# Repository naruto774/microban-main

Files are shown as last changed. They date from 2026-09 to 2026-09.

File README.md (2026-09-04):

# Microban: A Compact, Fully 3D-Printable Open-Source Humanoid Robot





<p align="center">
  
  
  
</p>
  
Welcome to the **Microban** project! 

Microban is a ~30cm tall open-source humanoid robot created by [Marc Duclusaud](https://github.com/MarcDcls) as a member of the Rhoban team at LaBRI, University of Bordeaux, and designed specifically for makers, students, and robotics enthusiasts. The core philosophy behind this project is accessibility: the total cost of the robot is kept relatively low ($550-$600), all components are 3D-printable or easily sourced, and the assembly process is guided with detailed instructions. This means that anyone with a standard desktop 3D printer and a few basic tools should be able to build their own Microban from scratch.

The idea behind Microban is to provide a platform for learning and experimentation in robotics. By making the design open, users are encouraged to modify, improve, and share their own versions of the robot. Whether you're interested in programming, mechanical design, or electronics, Microban offers a hands-on experience that can help you develop your skills in a fun and engaging way.

The main features of Microban are:
*   🤖 **100% Open-Design**: Mechanics, 3D models, and documentation are entirely free to use and modify.
*   🔧 **DIY & Maker Friendly**: Guided assembly instructions, fully 3D-printable parts and cheap components.
*   📏 **Compact Size**: Microban is only 30cm tall and can be recharged via USB-C, making it the perfect desktop companion for robotics experimentation.

To see the robot take its first steps, check out this YouTube video: [https://youtu.be/1pnFrT_jfXQ](https://youtu.be/1pnFrT_jfXQ)

---

## 🛠️ Components Overview

Here is a quick overview of what is in the robot:

| Component | Quantity | Description / Notes |
| :--- | :---: | :--- |
| **3D Printed Parts** | ~30 | Check the CAD files. Recommended material is PLA. |
| **Servo Motors** | 19 | Dynamixel XL330-M288-T servomotor. |
| **Microcontroller**| 1 | Raspberry Pi Zero 2W. |
| **Board Hat** | 1 | Pollen RPI Robot Hat for Raspberry Pi Zero 2W. |
| **Power Supply** | 2 | 18650 3.7V Lithium-ion Batteries. |
| **Battery Holder** | 1 | 2x18650 Battery Holder. |
| **USB-C Charger** | 1 | Standard USB-C charger. |
| **BMS** | 1 | Battery Management System for 2x18650 batteries. |
| **Plastic Screws**| ~200 | Standard plastic screws for assembly. |
| **Steel & POM Shims** | 12 | Alternative to needle bearings for motors without idler horns. | 

A full, detailed Bill Of Materials (BOM) with links to purchase and prices is available [here](docs/bom.md)

---

## 📁 CAD Files

Capture d’écran du 2026-06-15 13-33-16

The CAD files for Microban are in the `cad/` directory of this repository. It contains all the printable parts in both STL and STEP formats.

A visual representation of the 3D model can be found in the [Onshape assembly](https://cad.onshape.com/documents/d424992a192a8ce34ffce163/v/7de3e6e40f0e1185d169e6d9/e/b34620a03cc3a684006c5867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). This interactive assembly allows you to explore the robot's design in detail, providing a better understanding of how the parts fit together. It also serves as a reference for assembly, helping you visualize the final product and ensuring that you can correctly identify each component during the build process.

An emphasis is placed on the range of motion of the 19 degrees of freedom of the robot. It allows for a wide variety of movements, making it suitable for various applications. Stops are integrated into the design to control which self-collisions are likely to occur, ensuring that the robot can move safely without damaging itself. The design also takes into account the cable routing for the servo motors, ensuring that the wires are neatly organized and do not interfere with the robot's movements.

---

## 🚀 Getting Started 

> **Need help during the build?** 
> If you run into any issues while sourcing components, printing parts, or assembling your Microban, don't hesitate to ask the community in the **[Q&A Discussions section](https://github.com/Rhoban/microban/discussions/categories/q-a)**!

To build your own Microban, you will need to follow these steps:

1. **Source the hardware:** Gather the components listed in the [BOM](docs/bom.md). Links are provided to purchase each item, but feel free to source them from your preferred suppliers. Some components, like the Dynamixel motors, may have specific distributors depending on your location, which can impact the total cost. 

2. **Print the parts:** Head over to the `cad/stl/` folder and print all the parts using a 3D printer. The recommended filament is PLA with a layer height of 0.12mm and a 15% infill. Some parts require specific orientations for printing to ensure strength and proper fit. Refer to the [Printing Guide](docs/printing.md) for detailed instructions on how to print each part correctly.

3. **Assemble:** Follow our step-by-step [Assembly Guide](docs/assembly.md) to put the mechanics together.

4. **Deploy the software:** Once the robot is assembled, you can deploy the software on the Raspberry Pi Zero 2W by following the instructions in the [Deployment Guide](docs/deployment.md). 

5. **Drive it:** See the [Usage Guide](docs/usage.md) to run the robot, control it with the keyboard or a gamepad, and learn how to add your own moves.

---

## 🤝 Contributing

This project is community-driven! Whether it's designing a new head, writing code, or simply fixing typos in the documentation, contributions are always welcome. Feel free to fork the repository, make your changes, and submit a Pull Request. 

If you build your own Microban, don't hesitate to share it in the **[Show and Tell section](https://github.com/Rhoban/microban/discussions/categories/show-and-tell)**! 

If you just want to share ideas or chat about the project, you are also more than welcome to join the **[General Discussions](https://github.com/Rhoban/microban/discussions/categories/general)**.

---

## 📄 License & Commercial Use

Copyright (c) 2026 Marc Duclusaud.

This project uses a dual-licensing model to keep the project open for the community while protecting the author's work from unauthorized commercial exploitation.

* **Hardware & Documentation (CAD, STL, Docs):** Licensed under [CC BY-NC-SA 4.0](https://creativecommons.org/licenses/by-nc-sa/4.0/).
* **Software (Source Code):** Licensed under [GNU GPL v3](https://www.gnu.org/licenses/gpl-3.0.html).

To summarize the licenses:

* **Hobbyists, Makers & Researchers:** You are **100% free** to download, 3D-print, build, modify, and hack Microban for your personal, educational, or academic research use. If you share your modifications, you must release them under the same licenses.
* **Commercial Entities & Companies:** You **cannot sell this robot**, sell parts/kits, or use this hardware/software design in commercial products without prior explicit written permission.

### ⚠️ Commercial Inquiries

If you wish to manufacture, distribute, or sell products based on Microban (including selling pre-printed 3D parts, electronics kits, or fully assembled robots), you **must acquire a Commercial License**.

For licensing terms, commercial partnerships, or inquiries, please reach out to me on [LinkedIn](https://www.linkedin.com/in/marc-duclusaud/).

---

## 📚 Citation

If you use Microban in your research, please cite it as follows:

```bibtex
@software{mduclusaud-microban,
    author = {Duclusaud, Marc},
    doi = {10.5281/zenodo.20784789},
    month = jun,
    title = {{Microban: A Compact, Fully 3D-Printable Open-Source Humanoid Robot}},
    url = {https://github.com/Rhoban/microban},
    howpublished = "\url{https://github.com/Rhoban/microban}",
    version = {1.0.0},
    year = {2026}
}
```

---

<p align="center">
  
</p>

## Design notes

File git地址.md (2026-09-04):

# Git 远程仓库地址

## 仓库

- URL：https://github.com/naruto774/microban-main
- 可见性：Private
- 账号：`naruto774`
- 分支：`main`（已推送并跟踪 `origin/main`）

## 代理与 PATH（本机已配置）

| 配置项 | 值 |
|---|-----|
| 系统 / Git 代理 | `http://127.0.0.1:7897` |
| `gh` 路径 | `C:\Program Files\GitHub CLI\` |

当前终端若找不到 `gh`，先执行：

```powershell
$env:Path += ";C:\Program Files\GitHub CLI\"
$env:HTTP_PROXY = "http://127.0.0.1:7897"
$env:HTTPS_PROXY = "http://127.0.0.1:7897"
```

## 常用命令

```powershell
git pull
git push
gh repo view --web
```

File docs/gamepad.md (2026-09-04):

# Gamepad control through Bluetooth

The robot can be driven with a Bluetooth gamepad (Xbox or compatible). The gamepad
is paired with the Raspberry Pi and read directly there via the Linux joystick API
(`/dev/input/js*`), in the same process as the control loop. 

Pairing a gamepad allows to drive the robot through two different modes: with a terminal (SSH) or fully headless (no SSH, no terminal). The second mode is particularly useful for demonstration purposes, 
due to the fact that it allows to drive the robot without any computer connected to it. 

## Pairing the controller on the Pi

On the Pi, put the Xbox controller in pairing mode (hold the pair button until the
Xbox light flashes fast), then:

```
bluetoothctl
[bluetooth]# power on
[bluetooth]# agent on
[bluetooth]# scan on        # wait for the "Xbox Wireless Controller" MAC to appear
[bluetooth]# pair  XX:XX:XX:XX:XX:XX
[bluetooth]# trust XX:XX:XX:XX:XX:XX    # auto-reconnect on next power-on
[bluetooth]# connect XX:XX:XX:XX:XX:XX
[bluetooth]# scan off
[bluetooth]# quit
```

Once paired and trusted, the controller reconnects automatically when powered on.

## SSH usage

When the controller is connected, the `make run` command uses it as input automatically instead of the keyboard. The mapping is:

- **Left stick**: `vx` (up/down), `vy` (left/right)
- **Right stick** (left/right): `vtheta`
- **A**: toggle the `walk` move
- **B**: stop the scheduler (writes the stop flag)
- **View/Back** button: toggle the IMU/gyro display

Axis and button numbers vary between controllers (especially over Bluetooth) — if
something doesn't respond as expected, see [Remapping](#remapping-for-your-controller).

Every input source emits a **normalized** command in `[-1, 1]` per axis. The physical
limits are applied centrally by `scale_velocity()` in the scheduler, so they are
identical for keyboard, gamepad and sim: `vx` ±0.7, `vy` ±0.3, `vtheta` ±3.0 when
turning in place (`vx = vy = 0`) and ±1.5 while translating. Tune these via
`VX_MAX` / `VY_MAX` / `VTHETA_MAX_STATIONARY` / `VTHETA_MAX_MOVING` in
[constants.py](../src/constants.py).

Signs, deadzone and button mapping are constants at the top of
[gamepad_input.py](../src/input/gamepad_input.py); the move/button mapping is set
via `GAMEPAD_BUTTON_MOVES` in [main.py](../src/main.py).

## Headless mode (no SSH)

The headless mode is an optional service that lets you run the robot **without any terminal**. To activate it, power off the controller, then run the following commands on your computer:

```
make gamepad-headless-enable
```

Once enabled, it launches a daemon on the Pi that waits for a controller to connect over Bluetooth. Once a controller is connected, the Wi-Fi is turned off to free the 2.4 GHz antenna and the following commands are available on the controller:

- **Hold START** → start the control loop.
- **A** → toggle the `walk` move.
- **B** → stop the control loop.
- **Hold both triggers** → power off the Pi cleanly. Wait 10-15 s after that before
  flipping the robot's power switch off, to give the Pi time to actually halt.

The headless mode persists across reboots, which means that you don't need to connect to the Pi over SSH to enable it again. It is particularly useful for demonstration purposes, as it allows to drive the robot without any computer connected to it.

If the **controller disconnects** during a session, the robot's velocity is zeroed so
it stops moving (torque stays on, holding its pose). Reconnect and press **B** or power off the robot end the session.

Whenever the daemon is left with no controller connected — because it disconnected,
because the control loop crashed, or because the robot just booted — Wi-Fi is
(re)enabled automatically. You don't need to power-cycle the robot to get SSH back;
simply turning the controller off is enough.

> [!IMPORTANT]
> As the Wi-Fi is turned off when the controller is connected, so you won't be able to connect to the Pi over SSH while the controller is connected. If you need to connect to the Pi over SSH, power off the controller

To disable the headless mode, run the following command (after powering off the controller):
```
make gamepad-headless-disable
```

## Remapping for your controller

Xbox controllers don't all expose the same axis/button numbers — over Bluetooth the
kernel often uses a different layout than the wired `xpad` one. If a stick or button
doesn't behave as expected, find the real numbers and update the constants.

This requires an SSH session, so headless mode must be disabled first (see above) —
otherwise Wi-Fi is off while the controller is connected and you won't be able to
reach the Pi. You'll also need the controller connected.

1. Install the joystick package on the Pi:
```
sudo apt install -y joystick
```

2. Run `jstest /dev/input/js0`, then move each stick and press each button one at a
   time, noting the `Axis N` / `Button N` that changes:

   | Action | Note the number |
   | :--- | :--- |
   | Left stick horizontal / vertical | `Axis` → `_AXIS_LX` / `_AXIS_LY` |
   | Right stick horizontal | `Axis` → `_AXIS_RX` (drives `vtheta`) |
   | A / B / Back / Start | `Button` → `XBOX_BUTTONS` |
   | Left / right trigger | `Axis` → `TRIGGER_AXES` (headless power-off gesture) |

3. Edit the constants at the top of
   [gamepad_input.py](../src/input/gamepad_input.py):
   - `_AXIS_LX`, `_AXIS_LY`, `_AXIS_RX` — the stick axis numbers.
   - `XBOX_BUTTONS` — the button name → number map (at least the ones you use).
   - `TRIGGER_AXES` — the `LT` / `RT` axis numbers, and `TRIGGER_PRESS_THRESHOLD` —
     the raw axis value that counts as "pressed".
   - `VX_SIGN`, `VY_SIGN`, `VTHETA_SIGN` — flip between `+1.0` / `-1.0` if a direction
     is reversed.

4. Which button does what is set by `GAMEPAD_BUTTON_MOVES` in
   [main.py](../src/main.py) (moves) and the `stop_button` / `imu_button` arguments of
   `GamepadInputSource` (defaults: stop = `B`, IMU = `BACK`).

The defaults shipped in the repo (A=0, B=1, Start=11; left stick = axes 0/1, right
stick horizontal = axis 2, triggers = axes 4/5) are verified on an Xbox controller
over Bluetooth — but the exact axis numbers, rest/press values and button mappings are known to vary
across pads, so double-check with `jstest` on yours.

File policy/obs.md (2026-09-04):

针对 run `2026-08-27_14-43-05_motrix`（`run_config.json` 已确认：`empirical_normalization=true`，`action_scale=0.15`），整理如下。

---

## 1. 观测拼接代码

核心在 `MICROBANWalkEnv._compute_obs()`：

```407:463:src/unilab/envs/locomotion/microban/joystick.py
    def _compute_obs(
        self, info: dict, linvel, gyro, gravity, dof_pos, dof_vel
    ) -> dict[str, np.ndarray]:
        noise_cfg = self._cfg.noise_config
        diff = dof_pos - self.default_angles
        command = info["commands"]
        last_actions = info.get("current_actions", np.zeros_like(diff))
        gait_phase = info.get("gait_phase", np.zeros((self._num_envs, 2), dtype=get_global_dtype()))
        walk_profile = self._uses_walk_observation_profile()

        noisy_gyro = self._obs_noise(gyro, noise_cfg.scale_gyro)
        noisy_gravity = self._obs_noise(gravity, noise_cfg.scale_gravity)
        noisy_diff = self._obs_noise(diff, noise_cfg.scale_joint_angle)
        noisy_dof_vel = self._obs_noise(dof_vel, noise_cfg.scale_joint_vel)
        actor_gyro_scale = 0.25 if walk_profile else 1.0
        actor_dof_vel_scale = 0.05 if walk_profile else 1.0

        actor = np.concatenate(
            [
                noisy_gyro * actor_gyro_scale,
                -noisy_gravity,
                noisy_diff,
                noisy_dof_vel * actor_dof_vel_scale,
                last_actions,
                command,
                gait_phase,
            ],
            axis=1,
            dtype=get_global_dtype(),
        )
        # ... critic 分支省略 ...
        return {"obs": actor, "critic": critic}
```

传感器来源（`update_state`）：

```370:375:src/unilab/envs/locomotion/microban/joystick.py
        linvel = self.get_local_linvel()
        gyro = self.get_gyro()
        gravity = self._backend.get_sensor_data(self._cfg.sensor.upvector)
        dof_pos = self.get_dof_pos()
        dof_vel = self.get_dof_vel()
```

对应 `Sensor` 配置（`base.py`）→ XML 传感器名：

| 变量 | 传感器名 | XML 挂载 site |
|---|---|---|
| `gyro` | `trunk_gyro` | `body`（躯干原点） |
| `gravity` | `trunk_upvector` | `body` |
| `linvel`（仅 critic） | `trunk_local_linvel` | `body` |

---

## 2. Actor 观测 47 维布局（该 run 的实际缩放）

该 run 的 reward scales 含 `orientation / ang_vel_xy / action_rate`，因此 **`walk_profile = False`**，gyro/dof_vel **不做 0.25/0.05 缩放**。

| 索引 | 维度 | 内容 | 该 run 处理 |
|---|---|---|---|
| 0–2 | 3 | 角速度 `trunk_gyro` | `+ noise(×0.2)`，×**1.0** |
| 3–5 | 3 | 重力方向 | `-trunk_upvector`，`+ noise(×0.05)` |
| 6–17 | 12 | `dof_pos - default_angles` | `+ noise(×0.01)` |
| 18–29 | 12 | `dof_vel` | `+ noise(×1.5)`，×**1.0** |
| 30–41 | 12 | 上一步 action（`current_actions`） | 无噪声 |
| 42–44 | 3 | command `[vx, vy, ωz]` | 无噪声 |
| 45–46 | 2 | gait_phase `[φ_L, φ_R]` (rad) | 无噪声 |

**关节 / action 顺序**（与 actuator 一致，右腿在前）：

```
right_hip_yaw, right_hip_roll, right_hip_pitch, right_knee,
right_ankle_pitch, right_ankle_roll,
left_hip_yaw, left_hip_roll, left_hip_pitch, left_knee,
left_ankle_pitch, left_ankle_roll
```

**动作后处理**（部署需一致）：

\[
q_{\text{target}} = a \times 0.15 + q_{\text{default}}
\]

其中 `q_default` 来自 keyframe `stand` 的 ctrl（全 0，即 CAD 零位站立姿）。

**Command 范围**（训练采样，`vel_limit`）：

```
vx: [0.1, 0.40],  vy: [0.0, 0.0],  ωz: [-0.1, 0.1]
```

死区 `command_threshold=0.1` 内视为站立，command 清零、gait_phase 冻结。

---

## 3. ONNX input shape / metadata

导出路径：`scripts/train_rsl_rl.py` play 时调用 `runner.export_policy_to_onnx()`，写入 run 目录。该 run 下 **`policy.onnx` 已存在**。

RSL-RL 5.0.1 的 ONNX 封装（`_OnnxMLPModel`）规范：

| 字段 | 值 |
|---|-----|
| **input name** | `"obs"` |
| **input shape** | `(N, 47)`，trace 时用 `(1, 47)` |
| **output name** | `"actions"` |
| **output shape** | `(N, 12)` |
| **opset** | 18 |
| **normalization** | `empirical_normalization=true` → **Normalizer 已 bake 进图内**，部署侧喂**原始 47 维**（与训练拼接一致，**不加训练噪声**） |
| **output 语义** | Gaussian policy 的 **deterministic mean**（非采样） |

该 run 的 `run_config.json` 关键字段：

```json
"empirical_normalization": true,
"env.control_config.action_scale": 0.15,
"obs_groups": { "actor": ["actor"], "critic": ["critic"] }
```

**注意**：ONNX 图本身**不含** obs 布局 metadata（无 `deploy_config.yaml` 那种 segment 描述）；布局需按上文 47 维表手动对齐。Critic 的 50 维（含 linvel×1.0）**不会**导出到 policy ONNX。

---

## 4. 训练模型中 IMU 的安装位置

XML 里有两套 site，用途不同：

### A. 策略实际使用的传感器 — `body` site（躯干原点）

```65:67:src/unilab/assets/robots/microban/microban.xml
      <site group="3" name="body" pos="0 0 0" quat="1 -0 -0 -0"/>
      <!-- Frame imu -->
      <site group="3" name="imu" pos="0.01483 -0.002 0.0675" quat="0.5 -0.5 -0.5 0.5"/>
```

```38:40:src/unilab/assets/robots/microban/microban.xml
    <velocimeter site="body" name="trunk_local_linvel"/>
    <gyro site="body" name="trunk_gyro"/>
    <framezaxis objtype="site" objname="body" name="trunk_upvector"/>
```

**训练 policy 的 gyro / gravity 来自 `body` site（trunk 坐标系原点），不是 `imu` site。**

### B. 物理 IMU 建模 site — `imu` site（仅 XML 定义，未进 policy obs）

- **父 body**：`trunk`
- **相对 trunk 原点位置**：`(0.01483, -0.002, 0.0675)` m → **x=+14.8 mm，y=-2 mm，z=+67.5 mm**（约在躯干上部/胸廓区域）
- **姿态**：`quat="0.5 -0.5 -0.5 0.5"`（相对 trunk 有 90° 轴旋转）
- **挂载传感器**：`imu_ang_vel`、`imu_lin_vel`、`imu_accel`、`orientation`（framequat）

这些 **`imu_*` 传感器未接入 `_compute_obs()`**，当前 walk 策略观测与 **`body` 原点 IMU 等效**，而非真实 IMU 安装点。

---

## 5. 部署对齐 checklist

1. 按 47 维表拼接 obs（**无训练噪声**）
2. ONNX 输入 `(1, 47)` → 输出 `(1, 12)`
3. `q_target = action × 0.15 + default_angles`
4. 自研 IMU 若在 `(14.8, -2, 67.5) mm` 且 frame 与 XML `imu` quat 一致，需 **变换到 trunk 原点 frame** 才能与训练分布对齐；否则 sim-to-real 会有系统偏差

步态相位 **不是从足端接触或关节角反推的**，而是一个 **开环、固定频率的虚拟时钟**，由 env 在 `info["gait_phase"]` 里维护，再直接拼进观测的最后 2 维。

---

## 数学定义

记左右腿相位为 \(\phi_L, \phi_R \in [0, 2\pi)\)，每控制步更新：

\[
\begin{bmatrix} \phi_L \\ \phi_R \end{bmatrix}
\leftarrow
\left(
\begin{bmatrix} \phi_L \\ \phi_R \end{bmatrix}
+
\Delta\phi \cdot \mathbf{1}_{\|\mathbf{cmd}\| > \tau}
\right) \bmod 2\pi
\]

其中：

- \(\Delta\phi = 2\pi \cdot f_{\text{gait}} \cdot \Delta t\)
- \(f_{\text{gait}}\) = `reward.gait_frequency`（你的 run 为 **1.4 Hz**）
- \(\Delta t\) = `ctrl_dt`（Microban 为 **0.02 s**）
- \(\tau\) = `command_threshold`（**0.1**）
- \(\mathbf{cmd} = [v_x, v_y, \omega_z]\)

代入你的 run：

\[
\Delta\phi = 2\pi \times 1.4 \times 0.02 \approx 0.176 \text{ rad/step} \approx 10.1°/\text{step}
\]

---

## 代码流程

### 1. Reset 时初始化

默认 `gait_phase_init_mode = "offset_phase"`（左右腿相差 \(\pi\)，标准交替步态）：

```260:268:src/unilab/envs/locomotion/microban/joystick.py
    def _sample_gait_phase(self, env: Any, num_reset: int) -> np.ndarray:
        mode = env.cfg.gait_phase_init_mode
        if mode == "independent":
            left = np.random.uniform(0.0, 2.0 * np.pi, size=(num_reset,))
            right = np.random.uniform(0.0, 2.0 * np.pi, size=(num_reset,))
            return np.asarray(np.column_stack([left, right]), dtype=get_global_dtype())

        phase = np.random.uniform(0.0, 2.0 * np.pi, size=(num_reset,))
        return np.asarray(np.column_stack([phase, phase + np.pi]), dtype=get_global_dtype())
```

即：

\[
\phi_L \sim U[0, 2\pi),\quad \phi_R = \phi_L + \pi \pmod{2\pi}
\]

若 `mode == "independent"`，左右腿各自独立均匀采样。

### 2. 每步在 `apply_action` 里推进

```305:307:src/unilab/envs/locomotion/microban/joystick.py
        self._gait_phase_delta = float(
            2.0 * math.pi * self._reward_cfg.gait_frequency * cfg.ctrl_dt
        )
```

```652:666:src/unilab/envs/locomotion/microban/joystick.py
    def apply_action(self, actions: np.ndarray, state: NpEnvState) -> np.ndarray:
        ...
        moving = compute_gait_command_gate(
            state.info.get("commands", ...),
            self._cfg.command_threshold,
        )
        gait_phase = (gait_phase + self._gait_phase_delta * moving[:, None]) % (2 * np.pi)
        state.info["gait_phase"] = gait_phase
```

`moving` 判定：

```131:133:src/unilab/envs/locomotion/microban/joystick.py
def compute_gait_command_gate(commands: np.ndarray, threshold: float) -> np.ndarray:
    """Enable phase-driven gait behavior only for commands outside the stand deadzone."""
    return np.asarray(np.linalg.norm(commands, axis=1) > threshold, dtype=get_global_dtype())
\]

**站立时**（\(\|\mathbf{cmd}\| \le 0.1\)）：相位 **冻结**，不再递增。测试也验证了这一点。

### 3. 拼进观测

```414:432:src/unilab/envs/locomotion/microban/joystick.py
        gait_phase = info.get("gait_phase", np.zeros((self._num_envs, 2), dtype=get_global_dtype()))
        ...
        actor = np.concatenate(
            [
                ...
                command,
                gait_phase,   # obs[45:47] = [φ_L, φ_R]
            ],
```

观测里是直接喂 **原始弧度值**，没有 `sin/cos` 编码。

---

## 相位在 reward 里的语义（与 obs 共用同一变量）

同一 `gait_phase` 还通过 Bezier 曲线映射成左右脚 **期望摆动高度**，用于 `feet_phase` 等 reward：

```73:95:src/unilab/envs/locomotion/microban/joystick.py
def compute_feet_phase_height_targets(gait_phase, swing_height):
    # φ 归一化到 [-π, π)，再映射到 [0,1]
    phi_normalized = np.fmod(phi + np.pi, 2 * np.pi) - np.pi
    x = (phi_normalized + np.pi) / (2 * np.pi)
    # x ∈ [0, 0.5]: 支撑→抬脚;  x ∈ (0.5, 1]: 摆荡→落脚
```

直观理解一个周期（以单腿为例）：

| 相位区间 | 含义 |
|---|---|
| \(\phi \in [0, \pi)\) | 支撑相 → 抬脚（高度 0 → `swing_height`） |
| \(\phi \in [\pi, 2\pi)\) | 摆动相 → 落脚（高度 `swing_height` → 0） |

左右腿初始相差 \(\pi\)，所以一腿支撑时另一腿摆动。

---

## 部署侧注意

1. **必须自己维护** `gait_phase` 状态，不能指望 IMU/关节反推。
2. 用同一公式推进：\(\phi \leftarrow (\phi + \Delta\phi \cdot \mathbb{1}_{moving}) \bmod 2\pi\)。
3. `moving` 判定要与训练一致：command 范数 **> 0.1** 才推进。
4. Reset 时建议用 `offset_phase` 初始化（\(\phi_R = \phi_L + \pi\)），与训练分布一致。
5. 相位是 **理想时钟**，与实际足端触地可能不同步；策略学的是「跟着这个时钟走」。

如果你需要，我可以再写一段可直接用于 C++/Python 部署的 `gait_phase` 更新伪代码。

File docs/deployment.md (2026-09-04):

# Software Installation & Deployment

This guide takes you from the pre-built Microban SD-card image to a robot you can drive
from your computer. The image already contains the operating system and the Microban
code; you will flash it, connect to the robot over the network, and run it. For
day-to-day operation and development afterwards, see the [Usage Guide](usage.md).

## Step 1: Download and Flash the Image

Download `microban.img.xz` from the
[latest image release](https://github.com/MarcDcls/microban/releases/tag/image.v2)
([direct link](https://github.com/MarcDcls/microban/releases/download/image.v2/microban.img.xz)).
There is no need to decompress it; Raspberry Pi Imager reads the compressed `.xz`
directly.

Then use [Raspberry Pi Imager](https://www.raspberrypi.com/software/) to write
`microban.img.xz` onto a micro-SD card. The card should be 16 GB or larger, and I
advise using a new card, as corrupted cards can cause issues.

1. Insert the micro-SD card into your computer.
2. Open Raspberry Pi Imager. It is distributed as an AppImage, so make it executable
   and run it as root to let it write to the SD card:
   ```bash
   chmod +x Downloads/imager_*.AppImage
   sudo Downloads/imager_*.AppImage
   ```
3. **Choose Device** → *Raspberry Pi Zero 2 W*.
4. **Choose OS** → scroll to the bottom and select *Use custom*, then pick the
   `microban.img.xz` file.
5. **Choose Storage** → select your micro-SD card.
6. Click **Next**. When asked *"Would you like to apply OS customisation settings?"*,
   choose **No** — the image is already configured (the Wi-Fi is set up in Step 2).
7. Click **Write** and wait for the flashing and verification to complete.

> Alternatively, on Linux you can flash from the command line. **Double-check the
> device name** (`lsblk`) — writing to the wrong disk will erase it:
> ```bash
> xzcat microban.img.xz | sudo dd of=/dev/sdX bs=4M status=progress conv=fsync
> ```

## Step 2: Headless Wi-Fi Configuration

Once the flashing process is complete, unplug and plug back the micro-SD card into your Ubuntu PC.

Open your terminal and open the network configuration file using nano:

```bash
sudo nano /media/$USER/bootfs/network-config
```

You should see a YAML file with the following content:

```yaml
network:
  version: 2
  ethernets:
    eth0:
      dhcp4: true
      dhcp6: true
      optional: true
  wifis:
    wlan0:
      dhcp4: true
      regulatory-domain: "<YOUR_COUNTRY_CODE>"
      access-points:
        "<YOUR_WIFI_NAME>":
          password: "<YOUR_WIFI_PASSWORD>"
      optional: true
```

⚠️ CRITICAL: DO NOT modify the YAML format. It is strictly space-sensitive and should not be changed. 

📶 CRITICAL: the network **must be 2.4 GHz**. The Raspberry Pi Zero 2 W has a 2.4 GHz-only
Wi-Fi chip and **cannot see or join a 5 GHz network** — it will silently never connect. If
you use a phone hotspot, force it to 2.4 GHz.

🛜 Replace <YOUR_WIFI_NAME> and <YOUR_WIFI_PASSWORD> with your local network credentials. In addition, you can set other networks, such as your phone hotspot to use your robot everywhere. To do so, add an entry to the access-points section:

```yaml
      access-points:
        "<YOUR_WIFI_NAME>":
          password: "<YOUR_WIFI_PASSWORD>"
        "<YOUR_SECOND_WIFI_NAME>":
          password: "<YOUR_SECOND_WIFI_PASSWORD>"
```

🌍 Don't forget to replace <YOUR_COUNTRY_CODE> with your local two-letter country code (ISO 3166-1 alpha-2). For example, use "US" for the United States, "GB" for the United Kingdom, "FR" for France, "DE" for Germany, etc. This ensures the Raspberry Pi uses the correct Wi-Fi channels allowed in your country.

Save and exit (Ctrl + O, then Enter, then Ctrl + X).

Safely eject the card from your Ubuntu PC, insert it into the Raspberry Pi Zero 2W, and power it up.

> **Changing the Wi-Fi networks later:** just edit `network-config` again — on the Pi,
> or offline with the SD card in your PC — and reboot. The robot detects the change at
> boot and re-applies it automatically (it resets cloud-init and reboots once). 

## Step 3: First SSH Connection

Give the Raspberry Pi about 1 to 2 minutes on its very first boot. It will automatically resize the file system to use the full capacity of your SD card and then connect to your Wi-Fi network. Do not power it off during this process, as it may take a while and interrupting it could cause issues.

When the Pi is ready, you should be able to ping it from your computer using the command:

```bash
ping microban.local
```

You should see a response looking like this:
```
PING microban.local (192.168.XXX.XX) 56(84) bytes of data.
64 bytes from 192.168.XXX.XXX: icmp_seq=1 ttl=64 time=100 ms
...
```

The default credentials of this image are:
- Username: `user`
- Password: `password`

Open your terminal and connect over SSH:

```bash
ssh user@microban.local
```

> If `microban.local` cannot be found after 5 minutes, look up your local router's DHCP client list
> to find the IP address assigned to the Pi, and connect with `ssh user@<IP>`.

## Step 4: Personalize and Secure Your Robot

Once you are successfully connected via SSH, change the default password and,
optionally, customize the hostname.

### Change the password

Run the password tool and follow the prompts:
```bash
passwd
```

Apply the changes:
```bash
sudo reboot
```

### OPTIONAL - Change the username

The image ships with the user `user`. A logged-in account cannot be renamed, so create
a temporary admin account, rename from there, then remove it. Replace `NEW_USER` with
your choice.

From the default `user` session, create a temporary admin and set its password:
```bash
sudo useradd -m -s /bin/bash -G sudo tmpadmin
sudo passwd tmpadmin
```
Log out, reconnect as `tmpadmin`, then rename the original account:
```bash
ssh tmpadmin@<ROBOT_IP>
sudo usermod -l NEW_USER -d /home/NEW_USER -m user
sudo groupmod -n NEW_USER user      # rename its primary group too
```
Log out, reconnect as `NEW_USER`, and delete the temporary account:
```bash
ssh NEW_USER@<ROBOT_IP>
sudo userdel -r tmpadmin
```
The shutdown-without-password rule still works (it targets the `sudo` group, not a
name). Remember to update the `User` field in your `~/.ssh/config` (Step 5).

Apply the changes:
```bash
sudo reboot
```

### OPTIONAL - Change the hostname

Rename your robot so it no longer answers to `microban` on the network:
```bash
sudo hostnamectl set-hostname NEW_ROBOT_NAME
```
Then update the hosts file to match:
```bash
sudo nano /etc/hosts
```
Find the line containing `microban` (usually the second line) and replace it with your
`NEW_ROBOT_NAME`. Save and exit (Ctrl+O, Enter, Ctrl+X).

Apply the changes:
```bash
sudo reboot
```

## Step 5: Deploy the Software from Your Computer

The code already ships on the robot, but you drive and update it from your computer
using the provided `Makefile`, which syncs your local copy to the Pi over SSH and
installs the dependencies there.

1. **Install [uv](https://docs.astral.sh/uv/)** (the Python package manager) on your
   computer:
   ```bash
   curl -LsSf https://astral.sh/uv/install.sh | sh
   ```

2. **Clone the repository** on your computer:
   ```bash
   git clone https://github.com/MarcDcls/microban.git
   cd microban
   ```

3. **Add SSH aliases** so the Makefile can reach the Pi. Add the following to your
   `~/.ssh/config`, replacing `user` if you changed it and `<IP_ADDRESS>` with the
   robot's IP on each network:
   ```
   # Main network
   Host microban
       HostName <IP_ADDRESS>
       User user

   # Secondary network / phone hotspot
   Host microban-ext
       HostName <IP_ADDRESS>
       User user
   ```
   To find the robot's IP on a given network ping it from your computer while connected to that network:
   ```bash
   ping microban.local
   ```

   > The Makefile targets default to `HOST=microban`. To operate the robot over the
   > secondary network, pass `HOST=microban-ext` (e.g. `make run HOST=microban-ext`),
   > or export it for the whole session: `export HOST=microban-ext`.

4. **Copy your SSH key** (recommended) so you are not prompted for a password on every
   command:
   ```bash
   ssh-keygen -t ed25519     # skip if you already have a key
   ssh-copy-id microban
   ```

5. **Push the code and install dependencies** on the Pi:
   ```bash
   make setup
   ```
   This rsyncs your local copy to the robot and runs `uv sync --frozen` there.

## Step 6: Run the Robot

Your Microban is ready! Place it on a stable surface (or hold it securely), then start
the control loop from your computer:

```bash
make run
```

On start the robot enables torque and ramps to its neutral pose, then runs the control
loop at 50 Hz attached to your terminal. Press `q` or run `make stop` to stop.

🎉 For the full set of controls — Makefile commands, keyboard and gamepad driving,
the available moves, and how to add your own — see the **[Usage Guide](usage.md)**.

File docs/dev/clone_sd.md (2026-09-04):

# Cloning the SD card

This produces the distributable `microban.img.xz`. Do the **depersonalization** and **imaging** steps every time you cut a new image.

## Depersonalize before each clone

Right before imaging, remove everything personal/unique so each user gets a clean,
private robot. Power off the Pi, insert the SD into your PC, then (adjust the mount
paths if needed):

```bash
R=/media/$USER/rootfs

# SSH host keys — regenerated on first boot by regen-ssh-host-keys.service
sudo rm -f "$R"/etc/ssh/ssh_host_*

# machine-id — regenerated on first boot; ensures unique DHCP identity / IP per robot
sudo truncate -s 0 "$R/etc/machine-id"

# cloud-init instance state — clears the "already configured" flag so the user's
# network-config (Wi-Fi) is actually applied on their first boot. Without this,
# cloud-init treats the image as already set up and IGNORES network-config edits, so
# the robot never joins the user's network. (Equivalent to `cloud-init clean` on the Pi.)
sudo rm -rf "$R"/var/lib/cloud/instances/* "$R"/var/lib/cloud/instance \
            "$R"/var/lib/cloud/sem/* "$R"/var/lib/cloud/data/*

# netcfg watcher stamp — records the sha256 of the last-applied network-config
# (see setup_rasp.md, microban-netcfg-reapply.service). If left behind, it still
# holds YOUR network's hash, so the first user's identical-looking config can be seen
# as "unchanged" and the Wi-Fi never gets re-applied. Always clear it here.
sudo rm -f "$R"/var/lib/microban/netcfg.sha256

# Your Wi-Fi credentials (any NetworkManager connection you created).
sudo rm -f "$R"/etc/NetworkManager/system-connections/*.nmconnection

# Your SSH public key, shell history, caches and logs
sudo rm -f "$R/home/user/.ssh/authorized_keys"
sudo rm -f "$R/home/user/.bash_history"
sudo rm -f "$R"/var/cache/apt/archives/*.deb
sudo rm -rf "$R"/var/log/journal/* "$R"/var/log/*.log "$R"/var/log/*.gz
```

Reset the Wi-Fi config to placeholders so it does not ship with your network
credentials:
```bash
sudo tee /media/$USER/bootfs/network-config >/dev/null <<'EOF'
network:
  version: 2
  ethernets:
    eth0:
      dhcp4: true
      dhcp6: true
      optional: true
  wifis:
    wlan0:
      dhcp4: true
      regulatory-domain: "<YOUR_COUNTRY_CODE>"
      access-points:
        "<YOUR_WIFI_NAME>":
          password: "<YOUR_WIFI_PASSWORD>"
      optional: true
EOF
```

Also confirm the password is the documented default (`user` / `password`) and the
hostname is `microban`, so the image matches [the deployment guide](../deployment.md).

## Create and shrink the image

Go to gnome disks and create an image of the SD card.

Then shrink and compress it. The `-Z` flag compresses the shrunk image with `xz`
(turning a ~4 GB raw image into a few hundred MB), and `-a` runs the compression in
parallel across all CPU cores — much faster than the default single-threaded `xz`:
```
wget https://raw.githubusercontent.com/Drewsif/PiShrink/master/pishrink.sh
chmod +x pishrink.sh
sudo ./pishrink.sh -aZ ~/Documents/microban.img
```

This produces `~/Documents/microban.img.xz`. Check the final size with:
```
ls -lh ~/Documents/microban.img.xz
```

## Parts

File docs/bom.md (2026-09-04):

# Bill of Materials (BOM)

Here is a detailed Bill of Materials (BOM) for the project, including links to purchase each component and their approximate prices. Please note that prices may vary based on location and availability. You can source the components from your preferred suppliers, but beware that for electronic components using cheaper distributors may result in lower quality and reliability. 

Unlike the other components, the **[RPI Robot Hat](https://github.com/pollen-robotics/elec_RPI_Robot_HAT)** is not an off-the-shelf part: it is an open-source board that you need to have manufactured. Its design files are freely available on GitHub and can be ordered from any PCB fabrication service (e.g. JLCPCB, PCBWay, Aisler). The listed price is a rough estimate and will depend on the fab you choose and the quantity ordered. 

At the time of writing, **a Microban robot costs approximately $567**.

If you also include the configuration tools (Dynamixel U2D2 and U2D2 Power Hub), the total cost rises to approximately $623.

## Robot Components

To build a complete Microban robot, you will need the following components:

| Component | Image | Quantity | Price | Link | Description / Notes |
| :--- | :---: | :---: | :--- | :--- | :--- |
| Battery Holder |  | 1 | ~$5.00 | [Amazon](https://www.amazon.fr/gp/product/B08YDTSML8/ref=sw_img_1?smid=A9DEKVHK1XMRT&th=1) | 2x18650 Battery Holder. |
| BMS |  | 1 | ~$10.00 | [Amazon](https://www.amazon.fr/gp/product/B0GJLGG7MM/ref=ewc_pr_img_1?smid=A263J3XHEW00G8&psc=1) | Battery Management System for 2x18650 batteries. |
| Switch |  | 1 | ~$5.00 | [Amazon](https://www.amazon.fr/gp/product/B0F32NVDHW/ref=ewc_pr_img_1?smid=A3PA4HG72LIUMJ&psc=1) | Power switch for the robot. |
| Charger |  | 1 | ~$10.00 | [Amazon](https://www.amazon.fr/gp/product/B0BWTK7SVN/ref=ox_sc_act_title_1?smid=A25R4KS2AL1P7J&psc=1) | Standard USB-C charger. |
| Batteries |  | 2 | ~$4.00 each | [Nkon](https://www.nkon.nl/fr/sony-murata-us18650-vtc6.html) | 18650 3.7V Lithium-ion Batteries. Murata VTC6 are recommended but not mandatory. |
| Raspberry Pi Zero 2W |  | 1 | ~$15.00 | [Raspberry Pi](https://www.raspberrypi.com/products/raspberry-pi-zero-2-w/) | Microcontroller for the robot. |
| RPI Robot Hat |  | 1 | ~$30.00 | [GitHub](https://github.com/pollen-robotics/elec_RPI_Robot_HAT) | Open-source custom hat for the Raspberry Pi Zero 2W. The design files are available on GitHub and can be manufactured by any PCB fabrication service. |
| 16GB+ micro SD card |  | 1 | ~$10.00 | [Amazon](https://www.amazon.fr/-/en/SanDisk-microSDHC-Adapter-Performance-SDSQUA4-032G-GN6MA/dp/B08GY9NYRM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) | Class 10 micro SD card of at least 16GB for OS and software. |
| Dynamixel XL330-M288-T |  | 19 | $23.90 each | [Robotis](https://en.robotis.com/shop_en/item.php?it_id=902-0163-000) | Servomotor with 1 motor, 1 180mm cable, 10 2.2x8 screws, 6 2x6 screws. |
| M2x6 STP39 Screws |  | 10 | ~$3 (depends on quantity) | [Screwerk](https://de.screwerk.com/fr/shop/detail/stp/STP390200060S.html) | Screws for the motor horns. Self-tapping screws for plastic. Complete the screws from motor kits. |
| Filament material |  | <1 | ~$10.00 | Depends on the 3D printer | To print the robot parts. Less than one roll. |
| 20x30x1mm POM shims |  | 4 | ~$2.50 for 20 | [AliExpress](https://fr.aliexpress.com/item/1005006482475865.html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) | POM washers used as plain bearings. Alternative to needle bearings for motors without idler horns. |
| 25x30x0.3mm Steel shims |  | 8 | ~$1.75 for 10 | [AliExpress](https://fr.aliexpress.com/item/1005001878233881.html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) | Parts on which the POM shim rests. |
| M2.5x6 Screws |  | 18 | ~$3 (depends on quantity) | [Screwerk](https://de.screwerk.com/fr/shop/detail/stm/STM320200060S.html) | Standard M2.5x6 screws to attach the idle horns to the motors. Any standard should work. |

**Important Note:** The total number of M2x6 screws contained in 19 motor kits is 114, while the number of M2x6 screws required for the assembly is 124. If you buy more than 19 motors, you will have enough screws for the assembly. If you buy exactly 19 motors, you will need to buy 10 additional M2x6 screws. I personally recommend buying some additional M2x6 screws to avoid any issues during assembly. I also recommend buying M2.2x8 for the motor fixation, as the M2x8 screws provided with the motors may not fit perfectly, although they are usable. Check the [Optional Components](#optional-components) section for more details.

## Configuration Tools

In addition to the components that make up the robot, you will also need configuration tools to set up the Dynamixel motors:

| Component | Quantity | Price | Link | Description / Notes |
| :--- | :---: | :--- | :--- | :--- |
| Dynamixel U2D2 | 1 | $32.10 | [Robotis](https://en.robotis.com/shop_en/item.php?it_id=902-0132-000) | USB to Dynamixel adapter for motor configuration. |
| Dynamixel U2D2 Power Hub | 1 | $19.00 | [Robotis](https://en.robotis.com/shop_en/item.php?it_id=902-0145-001) | Power hub for U2D2. |
| 5V DC Power Supply | 1 | ~$5.00 | [AliExpress](https://fr.aliexpress.com/item/1005006681380264.html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) | 5V DC power supply for U2D2 Power Hub. Does not require a lot of current, it is only needed for the initial configuration. |

In case of building several robots, it is not necessary to buy several U2D2 sets, as they are only required for the initial configuration of the motors. 

## Optional Components

As discussed in the [Robot Components](#robot-components) section, I personally recommend replacing the provided M2x8 screws by M2.2x8 screws. For your information, the total amount of M2x6 self-tapping screws required for the assembly is 124, they are used to fix the horns to the parts. The total amount of M2x8 / M2.2x8 self-tapping screws required for the assembly is 66, they are used to fix the motors to the parts. Having extra screws can also be useful in case of loss.

The number of cables provided with the motors should be sufficient for the robot, but you may need additional cables in case of damage. 
It is also preferable to adjust the cable lengths to the minimum required for the robot to avoid cable entanglement. It is possible to only use off-the-shelf cables of size 50mm (6), 100mm (4), and 180mm (9), but due to the lack of availability, it is preferable to crimp your own cables. To do so, you can buy SEH-001T-P0.6 crimp pins and adjust 180mm cables to the required lengths. Detailed instructions on how to crimp your own cables will be provided in the Assembly Guide.

Finally, if you plan to use Microban intensively, you may want to consider having additional batteries and a charger to avoid downtime during charging. 

For all these reasons, here are some optional components you may want to consider:

| Component | Quantity | Price | Link | Description / Notes |
| :--- | :---: | :--- | :--- | :--- |
| Screws STP39 2x6 | 100 | ~$30 (depends on quantity) | [Screwerk](https://de.screwerk.com/fr/shop/detail/stp/STP390200060S.html) | Optional self-tapping screws for horn to part attachment. |
| Screws STP39 2.2x8 | 100 | ~$30 (depends on quantity) | [Screwerk](https://de.screwerk.com/fr/shop/detail/stp/STP390220080B.html) | Optional screws self-tapping for motor to part attachment. |
| Additional cables | 10 | $19.00 | [Robotis](https://en.robotis.com/shop_en/item.php?it_id=903-0249-000) | X3P cables for motors. Can be made with JST EHR-3 connectors. |
| SEH-001T-P0.6 | 100 | ~$5 | [AliExpress](https://fr.aliexpress.com/item/1005005433081646.html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) | JST EH crimp pin of size 2.50mm in roll. Compatible with JST EHR-3 connectors. |
| Crimp tool | 1 | ~$12 | [AliExpress](https://fr.aliexpress.com/item/1005003429462091.html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) | Crimping tool. Should contain a 1.9mm die for the SEH-001T-P0.6 crimp pin. |
| Additional batteries | 1 | ~$4 | [Nkon](https://www.nkon.nl/fr/sony-murata-us18650-vtc6.html) | 18650 3.7V Lithium-ion Batteries. Murata VTC6 are recommended but not mandatory. |
| 18650 Li-ion charger | 1 | ~$15 | [RS](https://fr.rs-online.com/web/p/chargeurs-de-batterie/1466770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) | Charger for 18650 Li-ion batteries. |

---

Once you have all the components, you can proceed to print the parts. Follow the [Printing Guide](printing.md) for detailed instructions.

If you already have the parts printed and the components purchased, you can directly proceed to the assembly of the robot by following the [Assembly Guide](assembly.md).

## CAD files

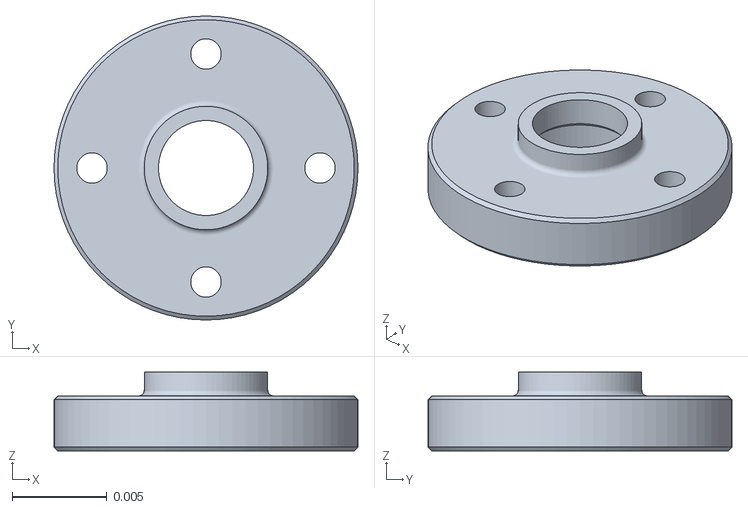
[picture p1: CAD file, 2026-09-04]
assets/assets/dc15_a01_horn_idle2_dummy.stl
0.016 x 0.016 x 0.00415

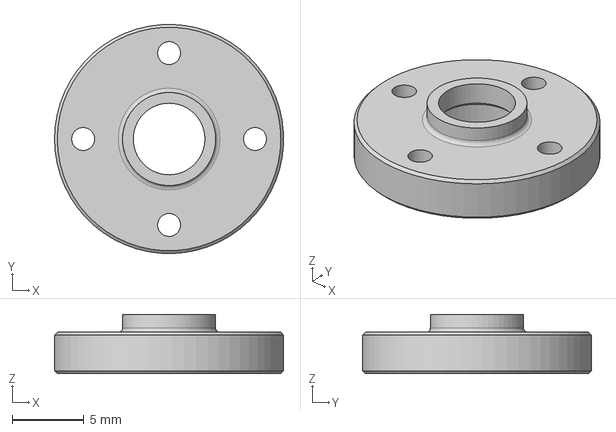
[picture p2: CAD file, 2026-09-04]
cad/step/idle_horn.step
16.0 x 16.0 x 4.15 mm

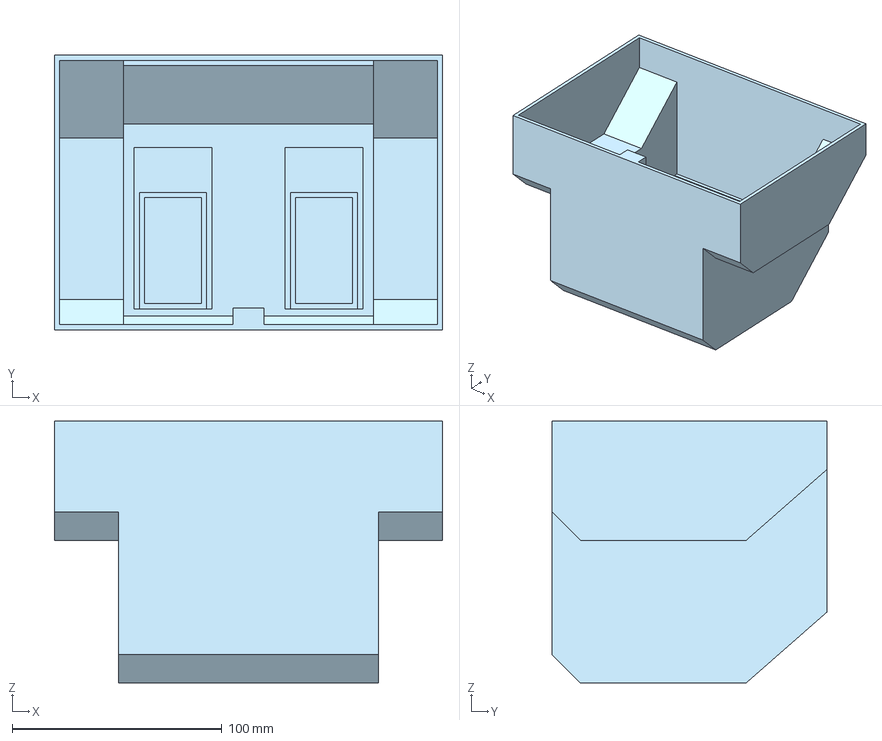
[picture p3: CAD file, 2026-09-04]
cad/step/optional/transport_case_lower.step
185.0 x 131.0 x 124.9 mm

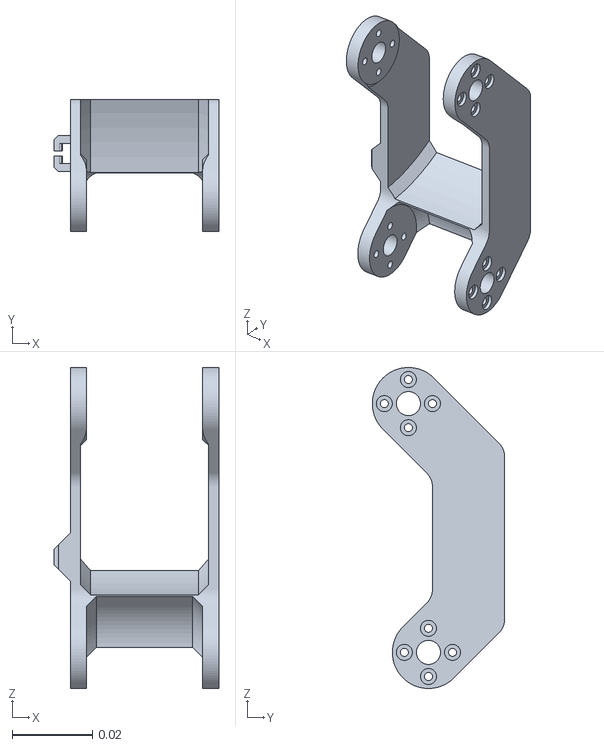
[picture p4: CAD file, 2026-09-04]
src/model/mjcf/assets/femur__configuration_left.stl
0.041 x 0.033 x 0.08

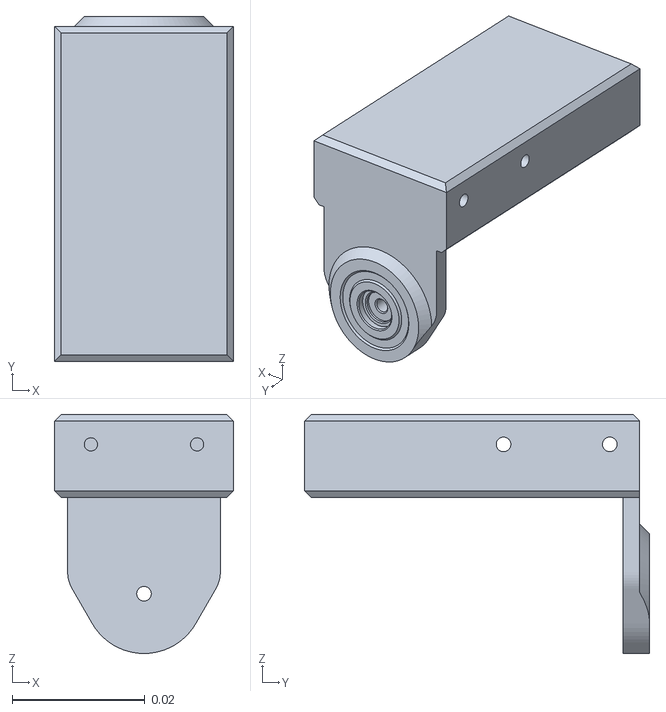
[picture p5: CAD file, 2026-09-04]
assets/assets/ankle_dbl_block__configuration_right.stl
0.027 x 0.052 x 0.036

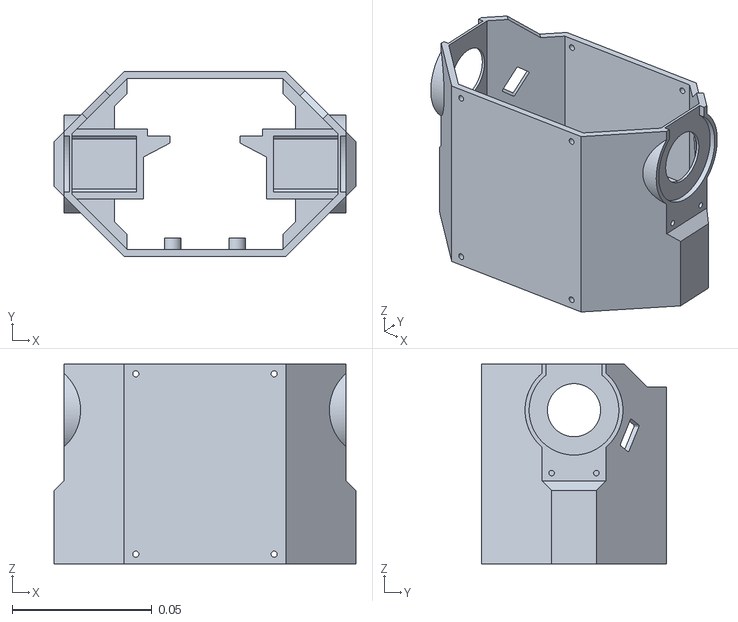
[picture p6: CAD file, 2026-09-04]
cad/mjcf/assets/chest__configuration_right.stl
0.108 x 0.066 x 0.0715

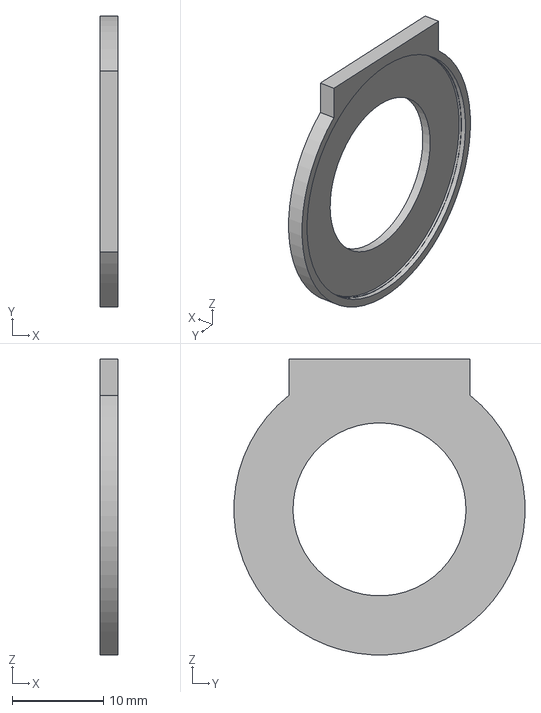
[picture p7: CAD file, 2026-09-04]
cad/step/arm_bearing_support.step
2.00 x 32.0 x 32.5 mm

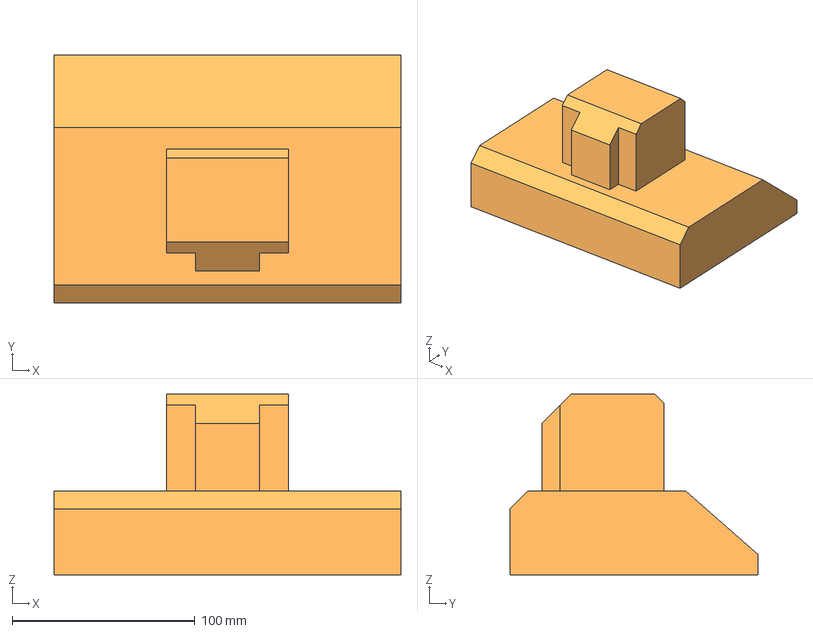
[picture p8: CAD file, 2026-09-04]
cad/step/optional/transport_case_upper.step
190.0 x 136.0 x 99.0 mm

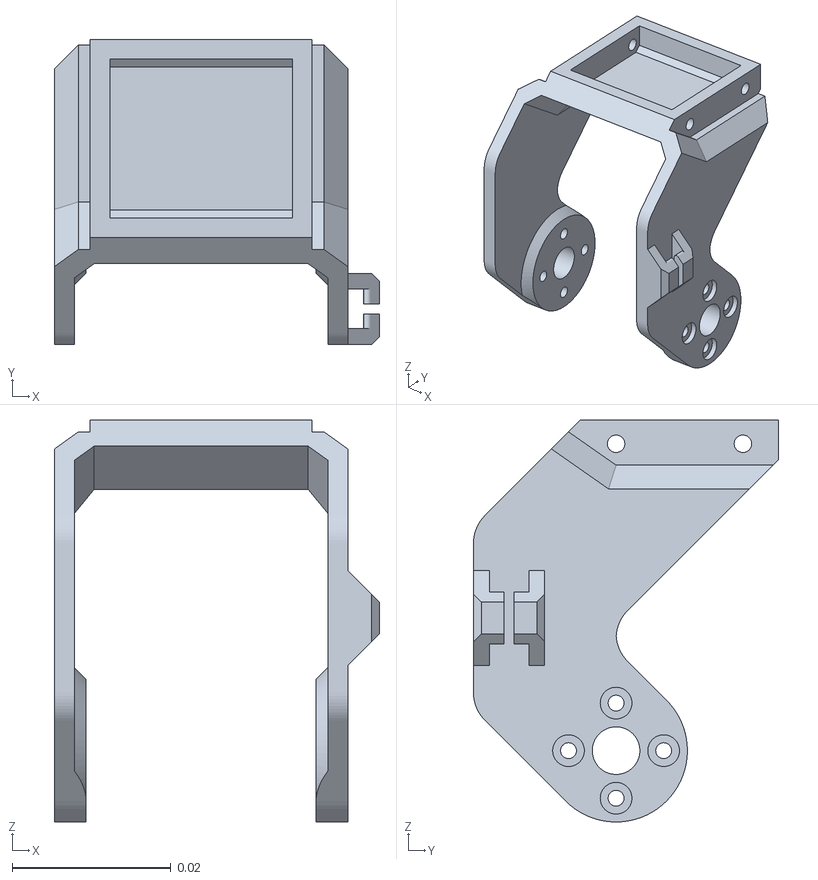
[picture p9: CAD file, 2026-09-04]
src/model/mjcf/assets/tibia__configuration_right.stl
0.041 x 0.0385 x 0.0507

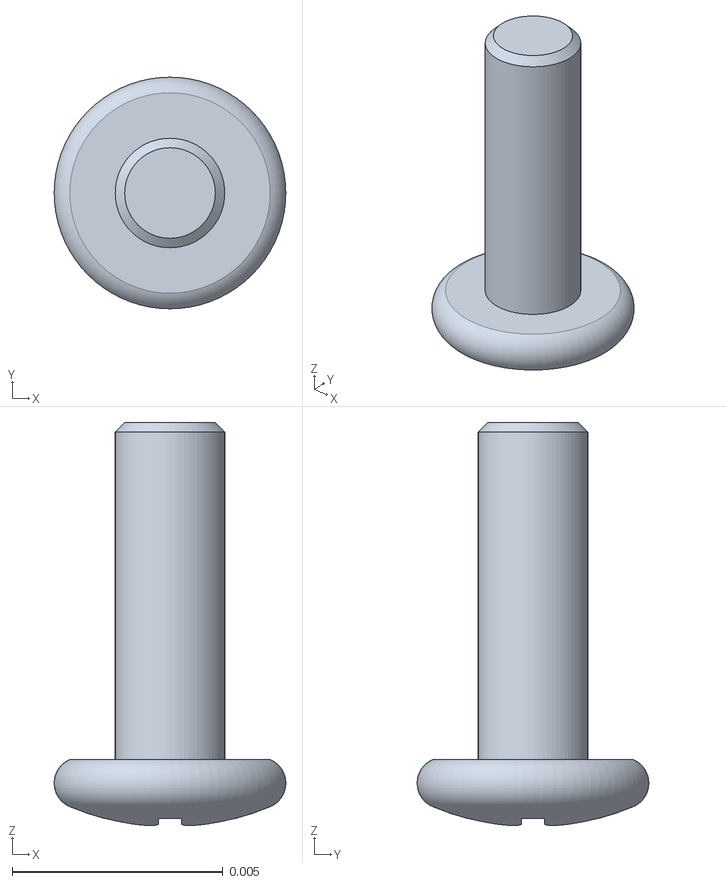
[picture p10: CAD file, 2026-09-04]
assets/assets/bts2_m2_6x8.stl
0.0055 x 0.0055 x 0.00957

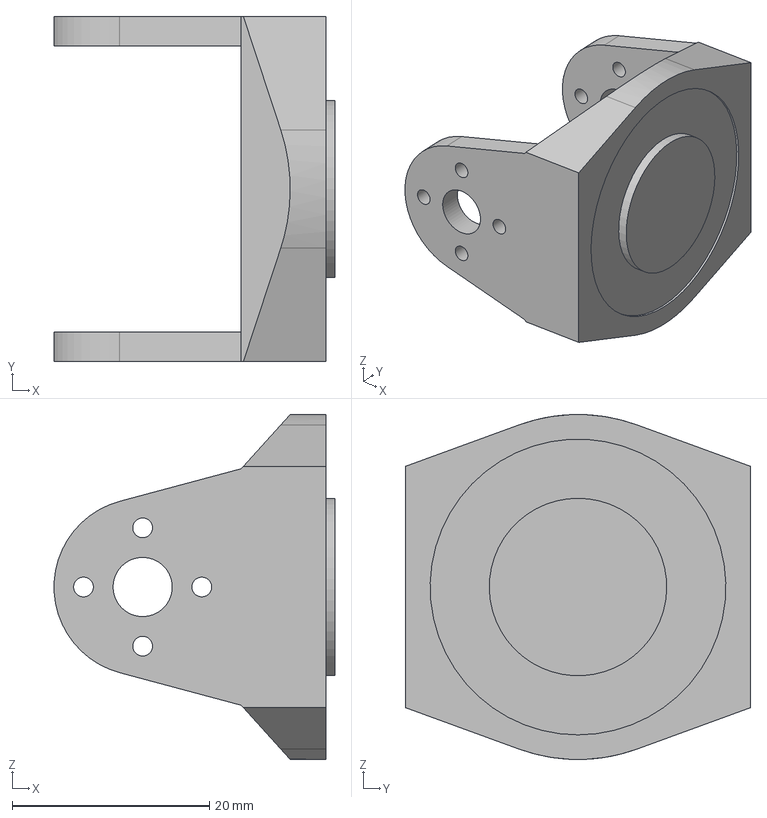
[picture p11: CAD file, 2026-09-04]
cad/step/shoulder.step
28.5 x 35.0 x 35.0 mm

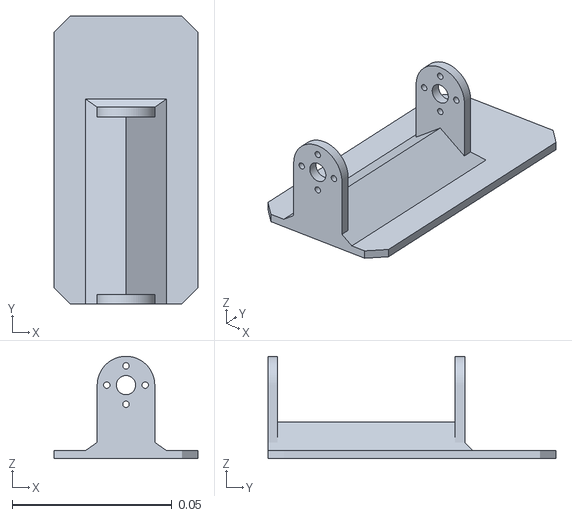
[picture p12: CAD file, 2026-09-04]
assets/assets/foot__configuration_right.stl
0.045 x 0.09 x 0.032

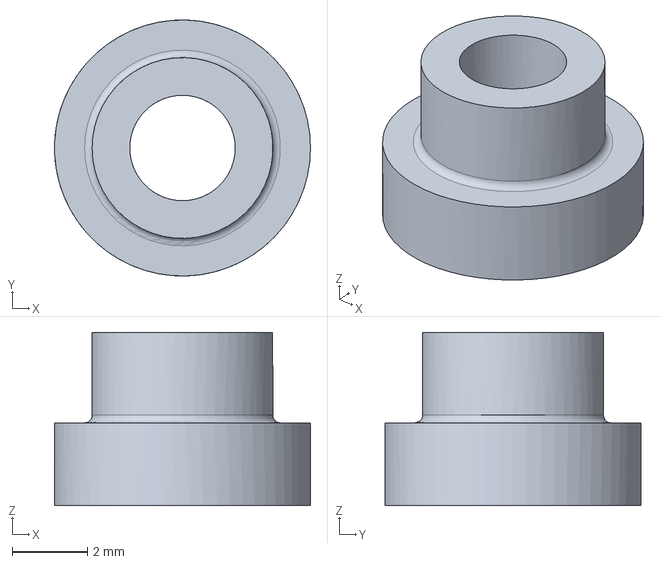
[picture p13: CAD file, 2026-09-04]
cad/step/idle_cap.step
6.80 x 6.80 x 4.60 mm

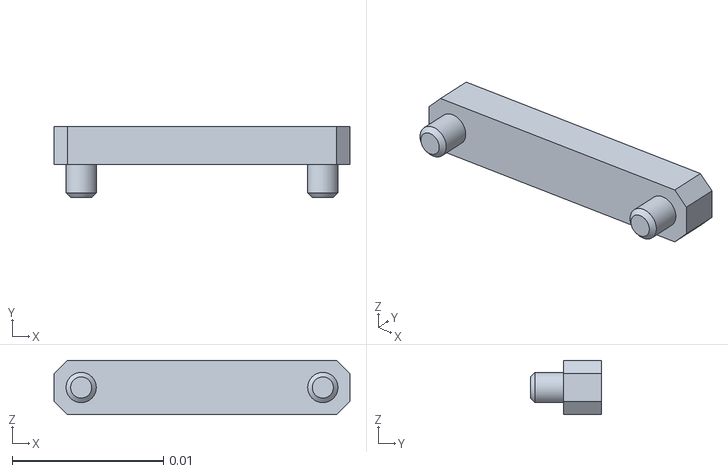
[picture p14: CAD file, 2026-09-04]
src/model/mjcf/assets/spacer__configuration_right.stl
0.0196 x 0.0047 x 0.0036

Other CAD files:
src/model/mjcf/assets/tibia__configuration_left.stl
assets/assets/ankle_dbl_block__configuration_right.scad
assets/assets/femur__configuration_left.scad
assets/assets/femur__configuration_right.scad
assets/assets/foot__configuration_right.scad
assets/assets/arm_bearing_support__configuration_right.stl
assets/assets/battery.stl
assets/assets/dc15_a01_idle_cap_dummy.stl
assets/assets/femur__configuration_right.stl
assets/assets/head__configuration_right.stl
assets/assets/hip__configuration_right.stl
assets/assets/hip_dbl_block__configuration_left.scad
assets/assets/hip_dbl_block__configuration_left.stl
assets/assets/hip_dbl_block__configuration_right.scad
assets/assets/hip_dbl_block__configuration_right.stl
assets/assets/humerus.stl
assets/assets/pelvis__configuration_right.scad
assets/assets/pelvis__configuration_right.stl
assets/assets/radius.scad
assets/assets/radius.stl
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

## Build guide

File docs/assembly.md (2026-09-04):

# Assembly Guide

This guide provides detailed instructions on how to assemble the parts for the Microban robot. Printing the parts and buying the necessary components are prequisites for this guide, so please refer to the [Printing Guide](printing.md) and the [BOM](bom.md) before starting the assembly process. 

At any point during the assembly, you can refer to the [Onshape assembly](https://cad.onshape.com/documents/d424992a192a8ce34ffce163/v/7de3e6e40f0e1185d169e6d9/e/b34620a03cc3a684006c5867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) to see how the parts fit together.

The steps to assemble the robot are as follows:
1. [Motor Setup](#1-motor-setup): Configure the motors using the Dynamixel Wizard software.
2. [Cable Setup](#2-cable-setup): Prepare all the cables necessary for the assembly. 
3. [Leg Assembly](#3-leg-assembly): Assemble the legs of the robot.
4. [Torso Assembly](#4-torso-assembly): Assemble the torso and arms of the robot.
5. [Electronics](#5-electronics): Assemble the top of the trunk, build the battery module, and connect the electronics.
6. [Final Assembly](#6-final-assembly): Assemble all the parts together to complete the robot.

---

## 1. Motor Setup

The first step in the assembly process is to set up the motors. I highly recommend writing the motor IDs directly on them to avoid mixing them up during configuration and assembly. The following table lists the motor names and their corresponding IDs:

| Motor Name | ID |
|---|----|
| Left Hip Yaw | 11 |
| Left Hip Roll | 12 |
| Left Hip Pitch | 13 |
| Left Knee | 14 |
| Left Ankle Pitch | 15 |
| Left Ankle Roll | 16 |
| Right Hip Yaw | 21 |
| Right Hip Roll | 22 |
| Right Hip Pitch | 23 |
| Right Knee | 24 |
| Right Ankle Pitch | 25 |
| Right Ankle Roll | 26 |
| Left Shoulder Pitch | 31 |
| Left Shoulder Roll | 32 |
| Left Elbow | 33 |
| Right Shoulder Pitch | 41 |
| Right Shoulder Roll | 42 |
| Right Elbow | 43 |
| Head | 51 |

To configure all the motors, connect one motor at a time to your PC using the U2D2 kit as presented in the image below. 



<br>
<br>

Then, launch [Dynamixel Wizard](https://emanual.robotis.com/docs/en/software/dynamixel/dynamixel_wizard2/). If your XL330 motor is not new, perform a factory reset by clicking on the "Recovery" button, selecting the XL-330-288 model and following the instructions. 

In the "Option" tab, select "Protocol 2.0", "57600 bps" as the baud rate, and verify that the correct COM port is selected. Then, click on the "Scan" button to detect the motor. Once the motor is detected, you can set the following parameters (and click on the "Save" button to save the settings):
- ID: the ID of the motor as listed in the table above
- Baud Rate: 3 (1Mbps)
- Return Delay Time: 0
- PWM Slope: 255 (no slope)
- Shutdown: 52 (Removing "Bit 0 Input voltage error")

Once the parameters are set, you can disconnect the motor and move on to the next one. If you want to check the motors at the end, you can connect them together as their IDs are set. You will need to change the baud rate of the scan to 1Mbps as it as been changed during the configuration. 

---

## 2. Cable Setup

The XL330 motors used in the Microban robot are daisy-chained, which means that the motors are connected in series. This allows to limit the number of cables that need to be routed through the robot. The only exception is near the board, where the first cables are split to connect to several links. The following diagram shows how the motors are connected to each other and to the board, and what cable lengths are used for each connection. 

routing

### 2.1 Splitter Cable

To create the 1-to-2 splitter cable, you can cut 2 cables of 180mm to obtain 3 half-cables of approximately 50mm (you don't need more length than that). Then, you can solder 2 of them to the 3rd one. Be careful to solder together the same wires, as an incorrect connection can damage permanently the motors. Do not forget to insulate the soldered connections with heat shrink tubing. 

To do the 1-to-3 splitter cable, the process is the same, but one of the 3 outgoing cables should be longer than the other two to allow for the robot opening from the top. So you should cut 2 cables of 180mm into 3 half-cables of approximately 50mm and one half-cable of approximately 120-130mm. 

The following images shows how the splitter cable should look like.



### 2.2 Reducing Cable Length

To reduce the length of the 180mm cables, you can cut them to the desired length and solder the ends back together, but it can lead to a weak connection and communication issues. A better solution is to re-crimp the cables to the desired length. To do this, you will need a crimping tool, JST EH crimp terminals, and optionally a wire stripper. You can check the [BOM](bom.md) for references.



<br>
<br>

First, cut the cable to the desired length. The end cut to the correct length should be stripped to expose the wires on 2mm, not more. While crimping the terminals, the first crimp will be done on the plastic part of the terminal to hold the wire in place, and the second crimp will be done on the metal part of the terminal to make the electrical connection. The details of the crimping process are presented in this [video](https://youtu.be/2hUjM0x_yfw).

<p align="center">
  
  
</p>

Once the 3 end terminals are crimped, you need to retrieve the plastic housing from the second half of the cable. You can do this by rising the plastic stops on the housing with a small screwdriver and pulling the housing out. If you have trouble with this step, here is another [video](https://youtu.be/mWsNwO4s6kE) showing how to do it. 

Finally, you can insert the 3 crimped terminals into the plastic housing. The order of the wires is important, so make sure to insert them in their corresponding position. Here is a last [video](https://youtu.be/w1A9wdLn3Ro) showing how to insert the terminals into the housing.

--- 

## 3. Leg Assembly

The objective of this section is to assemble the legs of the robot and fix them to the pelvis. 

<p align="center">
  
</p>

For the assembly, you should refer to the [Onshape assembly](https://cad.onshape.com/documents/d424992a192a8ce34ffce163/v/7de3e6e40f0e1185d169e6d9/e/b34620a03cc3a684006c5867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) to see how the parts fit together. Nevertheless, some parts of the assembly require specific instructions and are detailed in the following sub-sections.

### 3.1 Double-Motor Blocks

For the double-motor blocks used in the ankle and hip joints of the robot, you should pay attention to the cable routing, as the motors are very close to each other. Specifically, the cable connected to the bus between the two motors should be plugged before sliding the motors into the double-motor block. It concerns the cable relying the two motors, as well as the cable connecting the double-motor block to the next motor in the chain. The following images show you the assembly process on a right ankle double-motor block. 

Cable routing before sliding the motors into the double-motor block (do not forget the spacer):

<p align="center">
  
</p>

Result after sliding the motors into the double-motor block:

<p align="center">
  
  
</p>

### 3.2 Cable Routing 

For the cable lengths, refers to the [Cable Setup](#2-cable-setup) section. You should use the cable sockets on the tibia, femur and hip double-motor blocks to route the cables through the robot. 
For the tibia and femur routing, you can check the first image of the section. For the hip double-motor block, you can check the image below. 

<p align="center">
  
</p>

### 3.3 Feet Adhesion

To increase the adhesion of the feet to the ground, you can add an optional layer of rubber on the bottom of the feet. You can use a rubber sheet or cut a piece of an old cycling tire. 

<p align="center">
  
</p>

---

## 4. Torso Assembly

The objective of this section is to assemble the torso of the robot. 

<p align="center">
  
</p>

For the assembly, you should refer to the [Onshape assembly](https://cad.onshape.com/documents/d424992a192a8ce34ffce163/v/7de3e6e40f0e1185d169e6d9/e/b34620a03cc3a684006c5867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) to see how the parts fit together. 

Once the torso is assembled, you can fix it to the pelvis and connect the splitter cables to the hip yaw motors, shoulder pitch motors, and the RPI Robot Hat.

<p align="center">
  
</p>

---

## 5. Electronics

The objective of this section is to assemble the electronics of the robot, including the battery module and the trunk top. 

The following schematic shows how the electronics are connected together. The battery module is composed of a 2S 18650 battery holder and a BMS board. It is connected to the trunk top with a xt30 connector. The trunk top contains the USB-C charger and the switch powering on the Raspberry Pi. The routing allows to charge the battery independently of the power state of the robot. The alimentation of the Raspberry Pi is done through one of the 2 JST EHR-4 connectors on the RPI Robot Hat. 

microban_elec

### 5.1 Battery Module

To assemble the battery module, first connect the 4.2V pin of the BMS to the metal contact on the battery holder, located on the side opposite the red (8.4V) and black (0V) wires. To make this easier, you can melt a small hole in the holder using your soldering iron to reach and solder the wire to the contact. Next, solder the positive (+) and negative (-) wires from the BMS to the XT30 connector. Once the wiring is complete, secure the BMS to the back of the battery holder using double-sided tape. Finally, apply hot glue to insulate all the connections and prevent any short circuits. The pictures below show the fully assembled battery module.

<p align="center">
  
  
</p>

### 5.2 Trunk Top

First, insert the switch into the trunk top. Using pliers, carefully fold its pins down to free up some vertical space.

Next, prepare the JST EHR-4 power cable for the RPI Robot Hat. Cut a Dynamixel cable to a length of approximately 150mm and remove the two unused wires. Refer to the picture below to see which wires to keep.

<p align="center">
  
</p>

To wire the components, start by soldering the USB-C charger to the XT30 connector, which will be used to connect the battery module. Next, wire the switch by soldering the charger's **BAT** pin to one of its terminals, and the **VIN** wire of the JST EHR-4 cable to the other. Finally, complete the circuit by soldering the **GND** wire of the JST EHR-4 cable directly to the **GND** pin of the USB-C charger. 

The picture below shows the result of the wiring process.

<p align="center">
  
</p>

*Important:* Because the trunk top is printed in PLA (which is sensitive to heat), make sure to solder the USB-C charger module before mounting it to the plastic part. Also, once the wiring is complete, you should isolate the connections with hot glue to prevent any short circuits.

## 6. Final Assembly

To finalize the assembly of the robot, you just have to slide the battery module into the trunk, connect its XT30 connector to the trunk top, connect the JST EHR-4 cable to the RPI Robot Hat, and close the trunk with the trunk top. 

<p align="center">
  
  
</p>

<p align="center">
  WhatsApp Image 2026-06-25 at 18 08 36
</p>

If you have followed all the steps of this guide, your robot should be fully assembled and ready to be powered on. You can now proceed to the [Deployment Guide](deployment.md) to deploy the software on the Raspberry Pi and start controlling your Microban robot!

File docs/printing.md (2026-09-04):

# Printing Guide

This guide provides detailed instructions on how to print the parts for the Microban robot. It covers recommended settings, orientations, and tips to ensure successful prints. To see the full assembly of the parts, you can refer to the [Onshape assembly](https://cad.onshape.com/documents/d424992a192a8ce34ffce163/v/7de3e6e40f0e1185d169e6d9/e/b34620a03cc3a684006c5867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).

## Recommended Settings

The parts are available in the `cad/stl/` directory of this repository, and they are designed to be printed using a standard desktop 3D printer with PLA filament, 0.12mm layer height, and 15% infill. The next table summarizes the number of parts to print for each component of the robot. Please note that some parts may require specific orientations for printing, please refer to the [Part Orientation](#part-orientation) section for more details.

| Part | Quantity | Image | Description / Notes |
| :--- | :---: | :--- | :--- |
| foot.stl | 2 |  | Feet of the robot. |
| tibia_left.stl | 1 |  | Left tibia of the robot. Asymmetric to ensure proper cable routing. |
| tibia_right.stl | 1 |  | Right tibia of the robot. Asymmetric to ensure proper cable routing. |
| femur_left.stl | 1 |  | Left femur of the robot. Asymmetric to ensure proper cable routing. |
| femur_right.stl | 1 |  | Right femur of the robot. Asymmetric to ensure proper cable routing. |
| hip.stl | 2 |  | Hips of the robot. |
| ankle_dbl_block.stl | 2 |  | Double motor blocks for the ankle joint. |
| hip_dbl_block_left.stl | 1 |  | Left double-motor block for the hip joint. Asymmetric to ensure proper cable routing. |
| hip_dbl_block_right.stl | 1 |  | Right double-motor block for the hip joint. Asymmetric to ensure proper cable routing. |
| spacer.stl | 4 |  | Cable clearance spacers for ankle and hip double-motor blocks. |
| pelvis.stl | 1 |  | Pelvis of the robot. Lower part of the torso. |
| chest.stl | 1 |  | Chest of the robot. Middle part of the torso. |
| trunk_top.stl | 1 |  | Top part of the torso. |
| head.stl | 1 |  | The head of the robot. Currently just cosmetic, but can be modified to include sensors or cameras. |
| arm_bearing_support.stl | 2 |  | Supports for the shoulder shims. Printed separately from the chest to allow for better orientation and print quality. |
| shoulder.stl | 2 |  | Shoulder joints of the robot. |
| humerus.stl | 2 |  | Upper arms of the robot. |
| radius.stl | 2 |  | Lower arms of the robot. |
| idle_horn.stl | 4 |  | Idle horn for XL330 motors. This part can be bought from Robotis, but printing it does not affect the quality and is cheaper. |
| idle_cap.stl | 6 |  | Idle cap to fit the idle horn. This part can be bought from Robotis, but printing it does not affect the quality and is cheaper. Two of the caps are designed to fit the forearm parts (radius). |
| board_spacer.stl | 4 |  | Unthreaded spacer to place between the Raspberry Pi and the RPI Robot hat. | 

## Part Orientation 

The parts that support the plain bearings (POM washers sandwiched between steel shims) should be printed in a specific orientation to ensure proper fit and surface finish. These orientations can increase the required support material, but they are necessary to ensure that the bearings fit correctly and that the parts function as intended. These parts are: 
- `hip.stl`
- `pelvis.stl`  
- `arm_bearing_support.stl`
- `shoulder.stl`

The following parts also require specific orientations to ensure proper fit and alignment with the motors:
- `idle_horn.stl`
- `idle_cap.stl`
- `radius.stl`

The following images show the recommended orientations for the parts listed above.



<br>
<br>

For all the other parts, the orientation is quite straightforward, and they can be printed without the need of support material for a lot of them.

---

Once you have all the parts, if you already purchased the necessary components listed in the [BOM](bom.md), you can proceed to assemble the robot by following the [Assembly Guide](assembly.md).

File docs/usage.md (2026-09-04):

# Using Microban

This guide covers day-to-day operation once the robot has been set up (see the
[Deployment Guide](deployment.md)). You drive the robot from your computer with the
`Makefile`, which talks to the Pi over SSH. You can use the keyboard or a Bluetooth 
gamepad to control it, and optionally run it

> [!IMPORTANT]
> Always run `make shutdown` before cutting power to the robot. This is **not**
> automatic — powering off the Pi without a clean shutdown can corrupt the SD card.
> Wait 10-15 s after the command before flipping the power switch off, to give the
> Pi time to actually halt.

## Makefile commands

Run these from the repository root on your computer. They target the host `microban`
by default; add `HOST=microban-ext` to operate over the secondary network (see the
[Deployment Guide](deployment.md)).

| Command | What it does |
| :--- | :--- |
| `make run` | Sync the code and start the control loop on the robot (50 Hz). Stays attached to your terminal for live control. |
| `make stop` | Stop the control loop and disable torque on all motors. |
| `make shutdown` | Power off the Pi cleanly. |
| `make setup` | Sync the code and (re)install dependencies on the robot (`uv sync --frozen`). Run after changing dependencies. |
| `make sync` | Sync your local copy to the robot without touching dependencies. |
| `make imu` | Stream the robot's IMU/gyro readings to your terminal. |
| `make voltage` | Read the voltage of all motors. |
| `make voltage ID=<id>` | Read the voltage of motor `<id>`. |
| `make sim` | Run the MuJoCo simulation locally (no robot needed). |
| `make viewer` | Open the MuJoCo viewer locally (no robot needed). |

## Running the robot

1. Place the robot on a stable surface, or hold it securely — on start it enables
   torque and ramps to its neutral pose.
2. `make run` — the control loop starts at 50 Hz and stays attached to your terminal. Some latency is expected due to the SSH connection.
3. Toggle moves and drive the robot (see below).
4. `make stop` (or press `q`) to stop; `make shutdown` to power off.

## Controlling with the keyboard

| Key | Action |
| :--- | :--- |
| `v` | toggle the **walk** move |
| `h` | toggle the **head** move |
| `s` | toggle the **squat** move |
| arrows | `vx` (up/down), `vtheta` (left/right) |
| `x` | reset velocity to zero |
| `i` | toggle the IMU/gyro display |
| `q` | stop the control loop |

## Controlling with a gamepad

A Bluetooth Xbox controller can be used instead of the keyboard. The detailed explanation of the gamepad usage is in [Gamepad Guide](gamepad.md). 

Using a gamepad allows to drive the robot through two different modes: with a terminal (SSH) or fully headless (no SSH, no terminal). The second mode is particularly useful for demonstration purposes, due to the fact that it allows to drive the robot without any computer connected to it.

## Moves

Moves are toggled independently and run on top of the neutral pose:

- **Walk** (`v` / gamepad **A**) — a reinforcement-learning policy. Once active, the
  velocity command drives it: `vx` (forward/back), `vy` (lateral), `vtheta` (turn),
  set from the arrow keys or the gamepad sticks.
- **Head** (`h`) — oscillates the head.
- **Squat** (`s`) — squat motion computed with inverse kinematics.

### Velocity command

Every input source emits a **normalized** command in `[-1, 1]` per axis; the scheduler
maps it to physical limits with `scale_velocity()`, so the behavior is identical for
keyboard, gamepad and sim. Defaults (in [constants.py](../src/constants.py)):

| Axis | Max |
| :--- | :--- |
| `vx` (forward) | +0.7 |
| `vx` (backward) | -0.5 |
| `vy` (lateral) | ±0.3 |
| `vtheta` (turning in place, `vx = vy = 0`) | ±3.0 |
| `vtheta` (while translating) | ±1.5 |

## Developing: adding your own moves

Each behavior is a subclass of `Move` ([src/moves/move.py](../src/moves/move.py)) with
a simple lifecycle driven by the scheduler:

- `preload()` — optional, called once before the loop starts (load heavy resources).
- `on_start(obs, command)` — called each tick while *starting*; set
  `self.state = MoveState.ACTIVE` when ready (e.g. after ramping in).
- `step(obs, command)` — called each tick while *active*; write your target joint
  angles into `command.target_angles`.
- `on_stop(obs, command)` — called each tick while *stopping*; set
  `self.state = MoveState.INACTIVE` when done (e.g. after ramping back to neutral).

To add a move:

1. Create a new file in [src/moves/](../src/moves/) with a class subclassing `Move`.
   Use [rotate_head.py](../src/moves/rotate_head.py) (a simple oscillation) or
   [squat.py](../src/moves/squat.py) (inverse kinematics with placo) as a template.
2. Register it in [src/main.py](../src/main.py): add it to the `moves` dict passed to
   the `Scheduler`, and add a trigger — a key in `MOVE_KEYS` (keyboard) and/or a button
   in `GAMEPAD_BUTTON_MOVES` (gamepad).
3. In `step()`, read the robot state from `obs.robot_state` (motor positions and
   velocities, IMU gyro, projected gravity) and write your targets into
   `command.target_angles`.

### Training your own walk (or other RL) policies

The walk move runs an ONNX policy trained in simulation. 
You can train your own walking — or other learned skills — and drop the resulting `.onnx` file into [src/agents/](../src/agents/) to use it on the robot. Check the repository [MarcDcls/mjlab_microban](https://github.com/MarcDcls/mjlab_microban) for the training pipeline. 

If you achieve some interesting results, don't hesitate to make a pull request to the repository as it is also a community-driven project!

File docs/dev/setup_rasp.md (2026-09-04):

## Raspberry Pi setup

- Download the Raspberry Pi imager: https://www.raspberrypi.com/software/
- Plug your sd card in your computer
- Run it as sudo:

```
sudo Downloads/imager_[...].AppImage
```

- Select Raspberry Pi Zero 2 W
- Select Raspberry Pi OS (other)
- Select Raspberry Pi OS Lite (64-bit)
- Select your SD card
- Name it "microban"
- Select your timezone
- Set a username and a password
- Set the SSID and password of your local network (2.4 GHz)
- Activate SSH with password authentification
- Write

Once it's done, eject the SD card and plug it in your robot. It should boot and connect to your wifi. The first time it boots, it will take a while to expand the filesystem and install updates, so be patient and don't switch it off.

## Connecting to the Pi from your computer

To connect to your Raspberry Pi from your computer, it needs to be on the same network. 
Once on the same network, you can find the IP address of your Raspberry Pi by running:
```
ping microban.local
```

You should see a response looking like this:
```
64 bytes from 192.168.XXX.XXX: icmp_seq=1 ttl=64 time=100 ms
```

Then define a hostname for the Pi in your SSH config. To do this, add this entry to your `~/.ssh/config` file, with <USERNAME> being the username you set during the imager setup:
```
Host microban
    HostName 192.168.XXX.XXX
    User <USERNAME>
```

Finally, you can connect to the Pi with
```
ssh microban
```

In order not to have to enter the password everytime you connect to the Pi, you can copy your SSH key to the Pi. If you don't have an SSH key, you can generate one by running:
```
ssh-keygen -t ed25519
```

Then, copy your SSH key to the Pi with:
```
ssh-copy-id microban
```

Now you can connect to the Pi without entering a password!

## Raspberry Pi configuration

Copy the configuration file to the Pi. From your computer, run:
```
scp docs/dev/config.txt microban:config.txt
```

Then, on the Pi, move the configuration file to the correct location:
```
sudo mv config.txt /boot/firmware/config.txt
```

Reboot the Pi with `sudo reboot` for the changes to take effect.

After rebooting, connect to the Pi with `ssh microban` and setup the raspi-config:
- run `sudo raspi-config`
    - go to Interface Options
        - go to I2C
            - enable I2C    
        - go to Serial Port
            - disable Serial Console
            - enable Serial Port

Then, to prevent ssh hangs when the Pi is idle, run:
```
sudo nmcli con mod <tab_to_find_your_wifi_connection> wifi.powersave disable
```

Finally desactivate automatic updates by running 
```
sudo touch /etc/apt/apt.conf.d/99disable-auto-upgrades
cat << 'EOF' | sudo tee /etc/apt/apt.conf.d/99disable-auto-upgrades > /dev/null
APT::Periodic::Update-Package-Lists "0";
APT::Periodic::Download-Upgradeable-Packages "0";
APT::Periodic::AutocleanInterval "0";
APT::Periodic::Unattended-Upgrade "0";
EOF
```

Reboot the Pi with `sudo reboot`.

Install uv, the Python package manager, on the Pi. First, set the date:
```
sudo date -s "2026-06-27 12:21:00"
```

Then, run:
```
curl -LsSf https://astral.sh/uv/install.sh | sh
```

## SSH host-key regeneration

A distributed image must not ship with fixed SSH host keys — otherwise every robot
flashed from it shares the same keys (a security risk, and SSH host-key conflicts when
two robots run on the same network). We remove the keys before imaging (see below) and
let each robot regenerate its own on first boot.

Raspberry Pi OS already ships `sshd-keygen.service`, but it only runs when
`ConditionFirstBoot=yes` (i.e. `/etc/machine-id` is empty). Add a more robust service,
triggered by the **absence of host keys**, so they always regenerate when missing.

On the Pi (`ssh microban`):
```bash
sudo tee /etc/systemd/system/regen-ssh-host-keys.service >/dev/null <<'EOF'
[Unit]
Description=Regenerate SSH host keys if missing
Before=ssh.service ssh.socket sshd.service
ConditionPathExists=!/etc/ssh/ssh_host_ed25519_key

[Service]
Type=oneshot
RemainAfterExit=yes
ExecStart=/usr/bin/ssh-keygen -A

[Install]
WantedBy=multi-user.target
EOF

sudo systemctl enable regen-ssh-host-keys.service
```

## Wi-Fi re-application on change

`network-config` is read by cloud-init **only on the first boot**. So once a robot has
booted, editing `network-config` to switch Wi-Fi networks has no effect unless cloud-init
is reset. This service detects a changed `network-config` at boot and re-applies it
automatically, so a user can switch networks fully offline — edit `network-config` on the
SD card, boot, done — with no SSH or prior network access.

On the Pi (`ssh microban`):
```bash
sudo tee /usr/local/bin/microban-netcfg-reapply >/dev/null <<'EOF'
#!/bin/bash
# Re-apply /boot/firmware/network-config when it changes, by resetting cloud-init.
set -u

CFG=/boot/firmware/network-config
STAMP=/var/lib/microban/netcfg.sha256

[ -f "$CFG" ] || exit 0
mkdir -p "$(dirname "$STAMP")"

new=$(sha256sum "$CFG" | awk '{print $1}')
old=$(cat "$STAMP" 2>/dev/null || true)

if [ -z "$old" ]; then
    # First run: cloud-init already applied this config this boot. Just record it.
    echo "$new" > "$STAMP"
    exit 0
fi

if [ "$new" != "$old" ]; then
    # Config changed: record it, reset cloud-init, and reboot so cloud-init
    # re-applies the new network-config on the next boot.
    echo "$new" > "$STAMP"
    /usr/bin/cloud-init clean --logs
    /usr/sbin/reboot
fi
EOF
sudo chmod 755 /usr/local/bin/microban-netcfg-reapply

sudo tee /etc/systemd/system/microban-netcfg-reapply.service >/dev/null <<'EOF'
[Unit]
Description=Re-apply network-config (reset cloud-init) when it changes
After=cloud-final.service
ConditionPathExists=/boot/firmware/network-config

[Service]
Type=oneshot
ExecStart=/usr/local/bin/microban-netcfg-reapply

[Install]
WantedBy=multi-user.target
EOF

sudo systemctl enable microban-netcfg-reapply.service
```

## Serial console off, motor UART on fix

The Dynamixel motors are driven over the UART (`/dev/ttyAMA0`, 1 Mbps). The serial
**login console** must be **disabled** on that UART, otherwise the kernel and a getty
spew bytes onto the bus and the motors return checksum errors / stop responding. The
UART **hardware** must stay **enabled**.

⚠️ Setting this with `raspi-config` is **not enough on its own**: this image is driven
by cloud-init, whose `user-data` contains `rpi.interfaces.serial`. If it is set to
`true`, cloud-init **re-enables the serial console** every time it runs as a new
instance — which happens on every `cloud-init clean`, including the one the
`microban-netcfg-reapply` service triggers on a Wi-Fi change. So a raspi-config tweak
gets silently reverted and the motors break again.

Fix it at the source. Edit `/boot/firmware/user-data` and set the granular form
(console off, hardware on):
```yaml
rpi:
  interfaces:
    serial:
      console: false
      hardware: true
```
Validate the file, then apply it cleanly:
```bash
sudo cloud-init schema -c /boot/firmware/user-data   # must report "Valid schema"
sudo cloud-init clean && sudo reboot
```
After reboot, confirm `/proc/cmdline` no longer contains `console=ttyAMA0` and that the
motors answer (`rustypot_wizard` at 1 Mbps sees all 19 IDs). This config survives every
cloud-init re-run, so the motors stay reachable.

> If cloud-init rejects the granular form on your version, the fallback is to remove the
> `rpi.interfaces.serial` line entirely (cloud-init then leaves the serial alone) — the
> UART stays on via `enable_uart=1` in `config.txt`, and you disable the console once
> with `raspi-config` (Interface Options → Serial Port → login shell: No, hardware: Yes).

### Device permissions

Reading `/dev/input/js*` requires membership in the `input` group (otherwise you'd
need root):

```
sudo usermod -aG input $USER
```

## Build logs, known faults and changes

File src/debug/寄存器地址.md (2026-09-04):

Control Table of EEPROM Area
Address	Size(Byte)	Data Name	Access	Initial
Value	Range	Unit
0	2	Model Number	R	1,200	-	-
2	4	Model Information	R	-	-	-
6	1	Firmware Version	R	-	-	-
7	1	ID	RW	1	0 ~ 252	-
8	1	Baud Rate	RW	1	0 ~ 6	-
9	1	Return Delay Time	RW	250	0 ~ 254	2 [μsec ]
10	1	Drive Mode	RW	0	0 ~ 13	-
11	1	Operating Mode	RW	3	0 ~ 16	-
12	1	Secondary(Shadow) ID	RW	255	0 ~ 252	-
13	1	Protocol Type	RW	2	2 ~ 22	-
20	4	Homing Offset	RW	0	-1,044,479 ~
1,044,479	1 [pulse ]
24	4	Moving Threshold	RW	10	0 ~ 1,023	0.229 [rev/min]
31	1	Temperature Limit	RW	70	0 ~ 100	1 [°C]
32	2	Max Voltage Limit	RW	70	31 ~ 70	0.1 [V]
34	2	Min Voltage Limit	RW	35	31 ~ 70	0.1 [V]
36	2	PWM Limit	RW	885	0 ~ 885	0.113 [%]
38	2	Current Limit	RW	1,750	0 ~ 1,750	1 [mA ]
44	4	Velocity Limit	RW	445	0 ~ 2,047	0.229 [rev/min]
48	4	Max Position Limit	RW	4,095	0 ~ 4,095	1 [pulse]
52	4	Min Position Limit	RW	0	0 ~ 4,095	1 [pulse]
60	1	Startup Configuration	RW	0	3	-
62	1	PWM Slope	RW	140	1 ~ 255	1.977 [mV/msec]
63	1	Shutdown	RW	53	-	-
Control Table of RAM Area
Address	Size(Byte)	Data Name	Access	Initial
Value	Range	Unit
64	1	Torque Enable	RW	0	0 ~ 1	-
65	1	LED	RW	0	0 ~ 1	-
68	1	Status Return Level	RW	2	0 ~ 2	-
69	1	Registered Instruction	R	0	0 ~ 1	-
70	1	Hardware Error Status	R	0	-	-
76	2	Velocity I Gain	RW	1,600	0 ~ 16,383	-
78	2	Velocity P Gain	RW	180	0 ~ 16,383	-
80	2	Position D Gain	RW	0	0 ~ 16,383	-
82	2	Position I Gain	RW	0	0 ~ 16,383	-
84	2	Position P Gain	RW	400	0 ~ 16,383	-
88	2	Feedforward 2nd Gain	RW	0	0 ~ 16,383	-
90	2	Feedforward 1st Gain	RW	0	0 ~ 16,383	-
98	1	Bus Watchdog	RW	0	1 ~ 127	20 [msec]
100	2	Goal PWM	RW	-	-PWM Limit(36) ~
PWM Limit(36)	-
102	2	Goal Current	RW	-	-Current Limit(38) ~
Current Limit(38)	1 [mA]
104	4	Goal Velocity	RW	-	-Velocity Limit(44) ~
Velocity Limit(44)	0.229 [rev/min]
108	4	Profile Acceleration	RW	0	0 ~ 32,767
0 ~ 32,737	214.577 [rev/min2]
1 [ms]
112	4	Profile Velocity	RW	0	0 ~ 32,767	0.229 [rev/min]
116	4	Goal Position	RW	-	Min Position Limit(52) ~
Max Position Limit(48)	1 [pulse]
120	2	Realtime Tick	R	-	0 ~ 32,767	1 [msec]
122	1	Moving	R	0	0 ~ 1	-
123	1	Moving Status	R	0	-	-
124	2	Present PWM	R	-	-	-
126	2	Present Current	R	-	-	1 [mA]
128	4	Present Velocity	R	-	-	0.229 [rev/min]
132	4	Present Position	R	-	-	1 [pulse]
136	4	Velocity Trajectory	R	-	-	0.229 [rev/min]
140	4	Position Trajectory	R	-	-	1 [pulse]
144	2	Present Input Voltage	R	-	-	0.1 [V]
146	1	Present Temperature	R	-	-	1 [°C]
147	1	Backup Ready	R	-	0 ~ 1	-
168	2	Indirect Address 1	RW	224	64 ~ 251	-
170	2	Indirect Address 2	RW	225	64 ~ 251	-
172	2	Indirect Address 3	RW	226	64 ~ 251	-
…	…	…	…	…	…	…
218	2	Indirect Address 26	RW	249	64 ~ 251	-
220	2	Indirect Address 27	RW	250	64 ~ 251	-
222	2	Indirect Address 28	RW	251	64 ~ 251	-
224	1	Indirect Data 1	RW	0	0 ~ 255	-
225	1	Indirect Data 2	RW	0	0 ~ 255	-
226	1	Indirect Data 3	RW	0	0 ~ 255	-
…	…	…	…	…	…	…
249	1	Indirect Data 26	RW	0	0 ~ 255	-
250	1	Indirect Data 27	RW	0	0 ~ 255	-
251	1	Indirect Data 28	RW	0	0 ~ 255	-

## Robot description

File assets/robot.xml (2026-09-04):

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
<mujoco model="microban">
  <compiler angle="radian" meshdir="assets" autolimits="true"/>
  <default>
    <default class="microban">
      <joint frictionloss="0.1" armature="0.005"/>
      <position kp="50" dampratio="1"/>
      <default class="visual">
        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
      </default>
      <default class="collision">
        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
      </default>
    </default>
    <default class="xl330">
      <joint damping="0.041" frictionloss="0.013" armature="0.0018"/>
      <motor gear="1"/>
    </default>
  </default>
  <sensor>
    <framequat name="orientation" objtype="site" noise="0.001" objname="imu"/>
    <gyro name="angular-velocity" site="imu" noise="0.005"/>
    <gyro name="imu_ang_vel" site="imu"/>
    <velocimeter name="imu_lin_vel" site="imu"/>
    <accelerometer name="imu_accel" site="imu"/>
    <subtreeangmom name="root_angmom" body="trunk"/>
  </sensor>
  <worldbody>
    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
    <body name="trunk" pos="0 0 0" quat="1 0 0 0" childclass="microban">
      <freejoint name="trunk_freejoint"/>
      <inertial pos="-0.00454781 -0.000104579 0.053896" mass="0.347283" fullinertia="0.000608722 0.000477224 0.000357224 -5.1387e-07 -1.16287e-05 1.9299e-06"/>
      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
      <body name="head" pos="-0.00204165 -0 0.126" quat="0.707107 0 0 0.707107">
        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
        <joint axis="0 0 1" name="head" type="hinge" range="-1.5707963267949783 1.5707963267948148" class="xl330"/>
        <inertial pos="5.1303e-08 -0.0074561 0.0161837" mass="0.0166215" fullinertia="2.92963e-06 3.58354e-06 4.24694e-06 -1.6e-11 4e-12 2.61187e-07"/>
        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
      </body>
      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
      <body name="shoulder" pos="0 -0.0505 0.081" quat="0.707107 -0.707107 -0 0">
        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
        <joint axis="0 0 1" name="right_shoulder_pitch" type="hinge" range="-3.141592653589793 3.141592653589793" class="xl330"/>
        <inertial pos="4.19e-10 2.814e-09 -0.00850029" mass="0.00898451" fullinertia="1.06003e-06 1.78233e-06 1.86739e-06 0 0 -0"/>
        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
        <body name="humerus__configuration_right" pos="0.0145 0 -0.0195" quat="0 0.707107 0 0.707107">
          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
          <joint axis="0 0 1" name="right_shoulder_roll" type="hinge" range="-3.1415926535897922 8.881784197001252e-16" class="xl330"/>
          <inertial pos="-0.000309872 -0.0252784 -0.0143918" mass="0.0416867" fullinertia="1.76899e-05 3.95132e-06 1.75854e-05 -3.03216e-07 -2.278e-09 -7.8184e-08"/>
          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
          <body name="radius" pos="-0.0145 -0.0515 -0.0145" quat="0.707107 0 0.707107 -0">
            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
            <joint axis="0 0 1" name="right_elbow" type="hinge" range="-2.181661564992912 2.181661564992912" class="xl330"/>
            <inertial pos="-4.0628e-08 -0.0310611 0.0130165" mass="0.0115415" fullinertia="5.26775e-06 1.21602e-06 4.45903e-06 -4e-12 -1.2e-11 1.7157e-07"/>
            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
          </body>
        </body>
      </body>
      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
      <body name="hip" pos="0 -0.036 0" quat="1 -0 -0 0">
        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
        <joint axis="0 0 1" name="right_hip_yaw" type="hinge" range="-4.188790204786353 1.047197551196635" class="xl330"/>
        <inertial pos="0.00421822 1.46909e-07 -0.00948697" mass="0.00884451" fullinertia="9.36719e-07 4.32505e-06 4.03697e-06 -3.3e-11 1.95496e-07 0"/>
        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
        <body name="hip_block__configuration_right" pos="-0.02 0 -0.0214" quat="0.5 -0.5 0.5 -0.5">
          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
          <joint axis="0 0 1" name="right_hip_roll" type="hinge" range="-0.610865238197994 0.6108652381980366" class="xl330"/>
          <inertial pos="-5.75932e-05 0.00982795 0.0271518" mass="0.04763" fullinertia="1.64064e-05 1.33088e-05 7.85889e-06 -9.153e-09 7.8745e-08 6.63067e-07"/>
          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
          <body name="femur__configuration_right" pos="-0.0145 -0 0.0385" quat="0 0.707107 0 -0.707107">
            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
            <joint axis="0 0 1" name="right_hip_pitch" type="hinge" range="-1.5707963267948974 1.5707963267948957" class="xl330"/>
            <inertial pos="-0.0109472 -0.0366847 -0.0147025" mass="0.014726" fullinertia="1.12665e-05 4.38335e-06 8.95932e-06 -1.12592e-06 1.333e-09 -4.521e-09"/>
            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
            <body name="tibia__configuration_right" pos="-0.005 -0.062 -0" quat="1 -0 0 -0">
              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
              <joint axis="0 0 1" name="right_knee" type="hinge" range="-0.7853981633977201 2.356194490192073" class="xl330"/>
              <inertial pos="0.00276278 -0.0196679 -0.0144621" mass="0.0300463" fullinertia="1.53882e-05 5.3311e-06 1.38581e-05 2.25674e-06 7.6682e-08 -1.37001e-07"/>
              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
              <body name="ankle_block__configuration_left" pos="0.008 -0.0612131 -0" quat="0 -0 -0 1">
                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
                <joint axis="0 0 1" name="right_ankle_pitch" type="hinge" range="-1.5707963267948077 0.6108652381981041" class="xl330"/>
                <inertial pos="-0.0110676 -0.00979852 -0.0144015" mass="0.04722" fullinertia="7.83993e-06 1.29837e-05 1.60971e-05 -6.00742e-07 -4.9782e-08 -6.127e-09"/>
                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
                <body name="foot" pos="-0.0385 0 -0.0145" quat="0 -0.707107 0 -0.707107">
                  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
                  <joint axis="0 0 1" name="right_ankle_roll" type="hinge" range="-0.610865238197748 0.6108652381982826" class="xl330"/>
                  <inertial pos="-0 -0.0168869 0.0347422" mass="0.016823" fullinertia="1.15605e-05 1.2167e-05 2.53496e-06 0 -0 5.67932e-07"/>
                  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
                </body>
              </body>
            </body>
          </body>
        </body>
      </body>
      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
      <body name="shoulder_2" pos="-0 0.0505 0.081" quat="0 0 -0.707107 -0.707107">
        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
        <joint axis="0 0 1" name="left_shoulder_pitch" type="hinge" range="-3.141592653589793 3.141592653589793" class="xl330"/>
        <inertial pos="-4.19e-10 2.814e-09 0.00850029" mass="0.00898451" fullinertia="1.06003e-06 1.78233e-06 1.86739e-06 -0 0 0"/>
        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
        <body name="humerus__configuration_left" pos="-0.0145 0 0.0195" quat="0 -0.707107 -0 0.707107">
          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
          <joint axis="0 0 1" name="left_shoulder_roll" type="hinge" range="0.0 3.141592653589793" class="xl330"/>
          <inertial pos="-0.000313281 0.0252784 -0.0143884" mass="0.0416867" fullinertia="1.76899e-05 3.9512e-06 1.75853e-05 3.01684e-07 -5.77e-10 7.6531e-08"/>
          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
          <body name="radius_2" pos="-0.0145 0.0515 -0.0145" quat="0.707107 0 -0.707107 0">
            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
            <joint axis="0 0 1" name="left_elbow" type="hinge" range="-2.1816615649929156 2.1816615649929085" class="xl330"/>
            <inertial pos="-4.0628e-08 0.0310611 -0.0130165" mass="0.0115415" fullinertia="5.26775e-06 1.21602e-06 4.45903e-06 4e-12 1.2e-11 1.7157e-07"/>
            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
          </body>
        </body>
      </body>
      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
      <body name="hip_2" pos="-0 0.036 0" quat="0 -0 0 -1">
        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
        <joint axis="0 0 1" name="left_hip_yaw" type="hinge" range="-1.0471975511965976 4.1887902047863905" class="xl330"/>
        <inertial pos="-0.00421822 -1.46909e-07 -0.00948697" mass="0.00884451" fullinertia="9.36719e-07 4.32505e-06 4.03697e-06 -3.3e-11 -1.95496e-07 -0"/>
        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
        <body name="hip_block__configuration_left" pos="0.02 0 -0.0214" quat="0.5 -0.5 -0.5 0.5">
          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
          <joint axis="0 0 1" name="left_hip_roll" type="hinge" range="-0.6108652381980162 0.6108652381980144" class="xl330"/>
          <inertial pos="6.0554e-05 0.00982795 0.0271548" mass="0.04763" fullinertia="1.64096e-05 1.3312e-05 7.85888e-06 8.495e-09 -7.6959e-08 6.62404e-07"/>
          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
          <body name="femur__configuration_left" pos="-0.0145 -0 0.0385" quat="0.707107 -0 -0.707107 0">
            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
            <joint axis="0 0 1" name="left_hip_pitch" type="hinge" range="-1.5707963267948974 1.5707963267948957" class="xl330"/>
            <inertial pos="0.0109472 0.0366847 -0.0142975" mass="0.014726" fullinertia="1.12665e-05 4.38335e-06 8.95932e-06 -1.12592e-06 1.333e-09 -4.521e-09"/>
            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
            <body name="tibia__configuration_left" pos="0.005 0.062 0" quat="1 -0 -0 -0">
              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

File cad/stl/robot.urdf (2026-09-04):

<?xml version="1.0" ?>
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
<robot name="urdf">
  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
  <link name="trunk">
    <inertial>
      <origin xyz="-0.00454781 -0.000104579 0.053896" rpy="0 0 0"/>
      <mass value="0.347283"/>
      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
    </inertial>
    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
  </link>
  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
  <link name="body">
    <origin xyz="0 0 0" rpy="0 -0 0"/>
    <inertial>
      <origin xyz="0 0 0" rpy="0 0 0"/>
      <mass value="1e-9"/>
      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
    </inertial>
  </link>
  <joint name="body_frame" type="fixed">
    <origin xyz="0 0 0" rpy="0 0 0"/>
    <parent link="trunk"/>
    <child link="body"/>
    <axis xyz="0 0 0"/>
  </joint>
  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
  <link name="imu">
    <origin xyz="0 0 0" rpy="0 -0 0"/>
    <inertial>
      <origin xyz="0 0 0" rpy="0 0 0"/>
      <mass value="1e-9"/>
      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
    </inertial>
  </link>
  <joint name="imu_frame" type="fixed">
    <origin xyz="0.01483 -0.002 0.0675" rpy="1.5708 -0 -1.5708"/>
    <parent link="trunk"/>
    <child link="imu"/>
    <axis xyz="0 0 0"/>
  </joint>
  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
  <link name="head">
    <inertial>
      <origin xyz="5.1303e-08 -0.0074561 0.0161837" rpy="0 0 0"/>
      <mass value="0.0166215"/>
      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
    </inertial>
    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
  </link>
  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
  <joint name="head" type="revolute">
    <origin xyz="-0.00204165 -0 0.126" rpy="0 0 1.5708"/>
    <parent link="trunk"/>
    <child link="head"/>
    <axis xyz="0 0 1"/>
    <limit effort="10" velocity="10" lower="-1.5708" upper="1.5708"/>
  </joint>
  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
  <link name="shoulder">
    <inertial>
      <origin xyz="4.19e-10 2.814e-09 -0.00850029" rpy="0 0 0"/>
      <mass value="0.00898451"/>
      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
    </inertial>
    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
  </link>
  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
  <link name="humerus__configuration_right">
    <inertial>
      <origin xyz="-0.000309872 -0.0252784 -0.0143918" rpy="0 0 0"/>
      <mass value="0.0416867"/>
      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
    </inertial>
    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
  </link>
  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
  <link name="radius">
    <inertial>
      <origin xyz="-4.0628e-08 -0.0310611 0.0130165" rpy="0 0 0"/>
      <mass value="0.0115415"/>
      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
    </inertial>
    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
  </link>
  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
  <joint name="right_elbow" type="revolute">
    <origin xyz="-0.0145 -0.0515 -0.0145" rpy="-0 1.5708 0"/>
    <parent link="humerus__configuration_right"/>
    <child link="radius"/>
    <axis xyz="0 0 1"/>
    <limit effort="10" velocity="10" lower="-2.18166" upper="2.18166"/>
  </joint>
  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
  <joint name="right_shoulder_roll" type="revolute">
    <origin xyz="0.0145 0 -0.0195" rpy="-3.14159 -1.5708 0"/>
    <parent link="shoulder"/>
    <child link="humerus__configuration_right"/>
    <axis xyz="0 0 1"/>
    <limit effort="10" velocity="10" lower="-3.14159" upper="0"/>
  </joint>
  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
  <joint name="right_shoulder_pitch" type="revolute">
    <origin xyz="0 -0.0505 0.081" rpy="-1.5708 0 0"/>
    <parent link="trunk"/>
    <child link="shoulder"/>
    <axis xyz="0 0 1"/>
    <limit effort="10" velocity="10" lower="-3.14159" upper="3.14159"/>
  </joint>
  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
  <link name="hip">
    <inertial>
      <origin xyz="0.00421822 1.46909e-07 -0.00948697" rpy="0 0 0"/>
      <mass value="0.00884451"/>
      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
    </inertial>
    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
  </link>
  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
  <link name="hip_block__configuration_right">
    <inertial>
      <origin xyz="-5.75932e-05 0.00982795 0.0271518" rpy="0 0 0"/>
      <mass value="0.04763"/>
      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
    </inertial>
    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
  </link>
  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
  <link name="femur__configuration_right">
    <inertial>
      <origin xyz="-0.0109472 -0.0366847 -0.0147025" rpy="0 0 0"/>
      <mass value="0.014726"/>
      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
    </inertial>
    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
  </link>
  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
  <link name="tibia__configuration_right">
    <inertial>
      <origin xyz="0.00276278 -0.0196679 -0.0144621" rpy="0 0 0"/>
      <mass value="0.0300463"/>
      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
    </inertial>
    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
  </link>
  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
  <link name="ankle_block__configuration_left">
    <inertial>
      <origin xyz="-0.0110676 -0.00979852 -0.0144015" rpy="0 0 0"/>
      <mass value="0.04722"/>
      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
    </inertial>
    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
  </link>
  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
  <link name="foot">
    <inertial>
      <origin xyz="-0 -0.0168869 0.0347422" rpy="0 0 0"/>
      <mass value="0.016823"/>
      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
    </inertial>
    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
  </link>
  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
  <link name="right_foot">
    <origin xyz="0 0 0" rpy="0 -0 0"/>
    <inertial>
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

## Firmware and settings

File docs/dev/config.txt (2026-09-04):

# For more options and information see
# http://rptl.io/configtxt
# Some settings may impact device functionality. See link above for details

# Uncomment some or all of these to enable the optional hardware interfaces
dtparam=i2c_arm=on
dtparam=i2s=on
#dtparam=spi=on
# TLV320AIC3104 codec maxes out at 400 kHz on I2C; ToF/IMU work fine at this speed.
dtparam=i2c_arm_baudrate=400000

# Disable onboard BCM audio — we use the TLV320AIC3104 codec over I2S instead
dtparam=audio=off
dtoverlay=tlv320aic3x
dtoverlay=tlv320aic3104

# Additional overlays and parameters are documented
# /boot/firmware/overlays/README

# Automatically load overlays for detected cameras
camera_auto_detect=1
dtoverlay=imx500

# Automatically load overlays for detected DSI displays
display_auto_detect=1

# Automatically load initramfs files, if found
auto_initramfs=1

# Enable DRM VC4 V3D driver
dtoverlay=vc4-kms-v3d
max_framebuffers=2

# Don't have the firmware create an initial video= setting in cmdline.txt.
# Use the kernel's default instead.
disable_fw_kms_setup=1

# Run in 64-bit mode
arm_64bit=1

# Disable compensation for displays with overscan
disable_overscan=1

# Run as fast as firmware / board allows
arm_boost=1

[cm4]
# Enable host mode on the 2711 built-in XHCI USB controller.
# This line should be removed if the legacy DWC2 controller is required
# (e.g. for USB device mode) or if USB support is not required.
otg_mode=1

[cm5]
dtoverlay=dwc2,dr_mode=host

[all]
enable_uart=1
dtoverlay=miniuart-bt

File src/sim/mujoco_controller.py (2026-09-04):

# SPDX-License-Identifier: GPL-3.0-or-later
# Copyright 2026 Marc Duclusaud

import time
from collections import deque
from collections.abc import Callable
from pathlib import Path
from typing import TYPE_CHECKING

import mujoco
import mujoco.viewer

if TYPE_CHECKING:
    from sim.mujoco_input import MuJoCoInputSource

from bam.model import load_model as bam_load_model
from bam.mujoco import MujocoController as BamController

from constants import MOTOR_TO_ID, ID_TO_MOTOR, NEUTRAL_POSE, KP_DEFAULT, BAM_VIN, BAM_VOLTAGE_DROP_GAIN, BAM_VIN_MIN, BAM_MAX_CURRENT


class _DelayBuffer:
    """Returns values delayed by n_steps ticks (0 = no delay)."""

    def __init__(self, initial, n_steps: int) -> None:
        size = max(1, n_steps + 1)
        self._buf: deque = deque([initial] * size, maxlen=size)

    def push_and_read(self, value):
        self._buf.appendleft(value)
        return self._buf[-1]

    def fill(self, value) -> None:
        for i in range(len(self._buf)):
            self._buf[i] = value


class MuJoCoController:
    """MuJoCo-backed controller."""

    def __init__(
        self,
        mjcf_path: str,
        key_callback: Callable[[int, int, int, int], None] | None = None,
        stop_flag_path: str = "/tmp/microban_scheduler.stop",
        reset_source: "MuJoCoInputSource | None" = None,
        # Actuation delay (command → motor), in simulator steps (default timestep: 0.005 s)
        delay_act_steps: int = 0,
        # Sensor delays (motor/IMU → observation), in scheduler ticks (default: 0.02 s)
        delay_pos_ticks: int = 0,
        delay_vel_ticks: int = 0,
        delay_gyro_ticks: int = 0,
        delay_quat_ticks: int = 0,
        trunk_com_offset: tuple[float, float, float] = (0.0, 0.0, 0.0),
    ) -> None:
        self._stop_flag_path = Path(stop_flag_path)
        self._reset_source = reset_source
        self._model = mujoco.MjModel.from_xml_path(mjcf_path)
        self._data = mujoco.MjData(self._model)

        self._name_to_actuator_idx: dict[str, int] = {}
        self._name_to_qpos_idx: dict[str, int] = {}
        self._name_to_qvel_idx: dict[str, int] = {}
        for name in MOTOR_TO_ID:
            actuator_id = mujoco.mj_name2id(self._model, mujoco.mjtObj.mjOBJ_ACTUATOR, name)
            joint_id = mujoco.mj_name2id(self._model, mujoco.mjtObj.mjOBJ_JOINT, name)
            if actuator_id < 0:
                raise ValueError(f"Actuator '{name}' not found in MJCF model {mjcf_path!r}")
            if joint_id < 0:
                raise ValueError(f"Joint '{name}' not found in MJCF model {mjcf_path!r}")
            self._name_to_actuator_idx[name] = actuator_id
            self._name_to_qpos_idx[name] = self._model.jnt_qposadr[joint_id]
            self._name_to_qvel_idx[name] = self._model.jnt_dofadr[joint_id]
        # Number of physics sub-steps per scheduler tick (scheduler runs at 50 Hz)
        self._steps_per_tick = max(1, round(0.02 / self._model.opt.timestep))
        self._torque_interval = 0.1
        self._last_torque_print = 0.0

        # Apply CoM offset on trunk body (simulates inertial model error)
        if any(v != 0.0 for v in trunk_com_offset):
            trunk_id = mujoco.mj_name2id(self._model, mujoco.mjtObj.mjOBJ_BODY, "trunk")
            self._model.body_ipos[trunk_id, 0] += trunk_com_offset[0]
            self._model.body_ipos[trunk_id, 1] += trunk_com_offset[1]
            self._model.body_ipos[trunk_id, 2] += trunk_com_offset[2]

        # Set initial pose to neutral so the robot starts upright
        self._data.qpos[2] = 0.165
        for name, angle in NEUTRAL_POSE.items():
            if name in self._name_to_qpos_idx:
                self._data.qpos[self._name_to_qpos_idx[name]] = angle
        mujoco.mj_forward(self._model, self._data)

        # Delay buffers — simulate sensor/communication latency
        self._delay_pos = {
            mid: _DelayBuffer(
                self._data.qpos[self._name_to_qpos_idx[ID_TO_MOTOR[mid]]],
                delay_pos_ticks,
            )
            for mid in MOTOR_TO_ID.values()
        }
        self._delay_vel = {
            mid: _DelayBuffer(0.0, delay_vel_ticks)
            for mid in MOTOR_TO_ID.values()
        }
        self._delay_gyro = _DelayBuffer((0.0, 0.0, 0.0), delay_gyro_ticks)
        self._delay_quat = _DelayBuffer((1.0, 0.0, 0.0, 0.0), delay_quat_ticks)
        self._delay_act = {
            mid: _DelayBuffer(
                self._data.qpos[self._name_to_qpos_idx[ID_TO_MOTOR[mid]]],
                delay_act_steps,
            )
            for mid in MOTOR_TO_ID.values()
        }

        # BAM motor model — XL330 m6 (DC motor + Stribeck + load-dependent friction)
        bam_model = bam_load_model(motor_name="xl330", model="m6")
        bam_model.actuator.kp = KP_DEFAULT
        bam_model.actuator.vin = BAM_VIN
        self._bam = BamController(
            bam_model,
            list(MOTOR_TO_ID.keys()),
            self._model,
            self._data,
            vin_drop_gain=BAM_VOLTAGE_DROP_GAIN,
            vin_min=BAM_VIN_MIN,
            max_current=BAM_MAX_CURRENT,
        )
        self._bam.reset(self._data.qpos)

        self._viewer = mujoco.viewer.launch_passive(
            self._model, self._data, key_callback=key_callback
        )

        # Sensor indices for IMU readout
        self._sensor_orientation = mujoco.mj_name2id(self._model, mujoco.mjtObj.mjOBJ_SENSOR, "orientation")
        self._sensor_gyro = mujoco.mj_name2id(self._model, mujoco.mjtObj.mjOBJ_SENSOR, "angular-velocity")

    @property
    def viewer_opt(self) -> mujoco.MjvOption:
        return self._viewer.opt

    def set_kp(self, kp: float) -> None:
        self._bam.model.actuator.kp = kp

    def sync_read_kp(self, ids: list[int]) -> list[int]:
        kp = int(self._bam.model.actuator.kp)
        return [kp] * len(ids)

    def sync_write_kp(self, ids: list[int], gains: list[int]) -> None:
        self._bam.model.actuator.kp = gains[0]

    def sync_write_torque_enable(self, ids: list[int], values: list[bool]) -> None:
        pass

    def sync_write_status_return_level(self, ids: list[int], levels: list[int]) -> None:
        pass

    def sync_write_goal_position(self, ids: list[int], positions: list[float]) -> None:
        if not self._viewer.is_running():
            self._stop_flag_path.write_text("stop\n", encoding="ascii")
            return

        cmd = dict(zip(ids, positions))

        for _ in range(self._steps_per_tick):
            for motor_id, pos in cmd.items():
                delayed_pos = self._delay_act[motor_id].push_and_read(pos)
                self._bam.set_q_target(ID_TO_MOTOR[motor_id], delayed_pos)
            self._bam.update()
            mujoco.mj_step(self._model, self._data)

        if self._reset_source is not None and self._reset_source.consume_reset():
            self.reset()
            return
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

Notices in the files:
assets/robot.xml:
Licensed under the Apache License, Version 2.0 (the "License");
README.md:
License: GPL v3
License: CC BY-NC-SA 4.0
